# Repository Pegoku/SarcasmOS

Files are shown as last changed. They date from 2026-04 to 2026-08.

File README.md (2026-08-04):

# SarcasmOS

SarcasmOS is a personality-first voice assistant.
The core idea is simple: take a smart assistant like Alexa or Google Home, then give it a face, a voice, and most importantly, a personality. Instead of answering like a neutral corporate box, SarcasmOS replies in Spanish with dry humor, sarcasm, and animated expressions inspired by [Bender](https://futurama.fandom.com/wiki/Bender).

This project focusses on the software and AI side of the assistant, but it also includes various hardware elements, like multiple PCBs, sensors, motors, and quite a bit of 3D printing.
The goal is to have a memorable, sarcastic, and show-like assistant that can be used both for fun and real tasks like controlling smart home devices, playing music reviewing your agenda, or answering questions.

### Demo Video

Watch the SarcasmOS demo (https://www.youtube.com/watch?v=0U2ITrU95Sk)

<details>
  <summary>Do not click here</summary>

SarcasmOS striking a funny Bender pose

</details>

## Why did we Build This?

Futurama is a classic tv show we love (and you should too). Bender is the most memorable character, and his sarcastic personality is a perfect fit for a voice assistant.
We wanted to build a voice assistant that is not just a plain, neutral box, but one that has a personality and you won't just use it to get things done, but also to have fun and be entertained

## Images

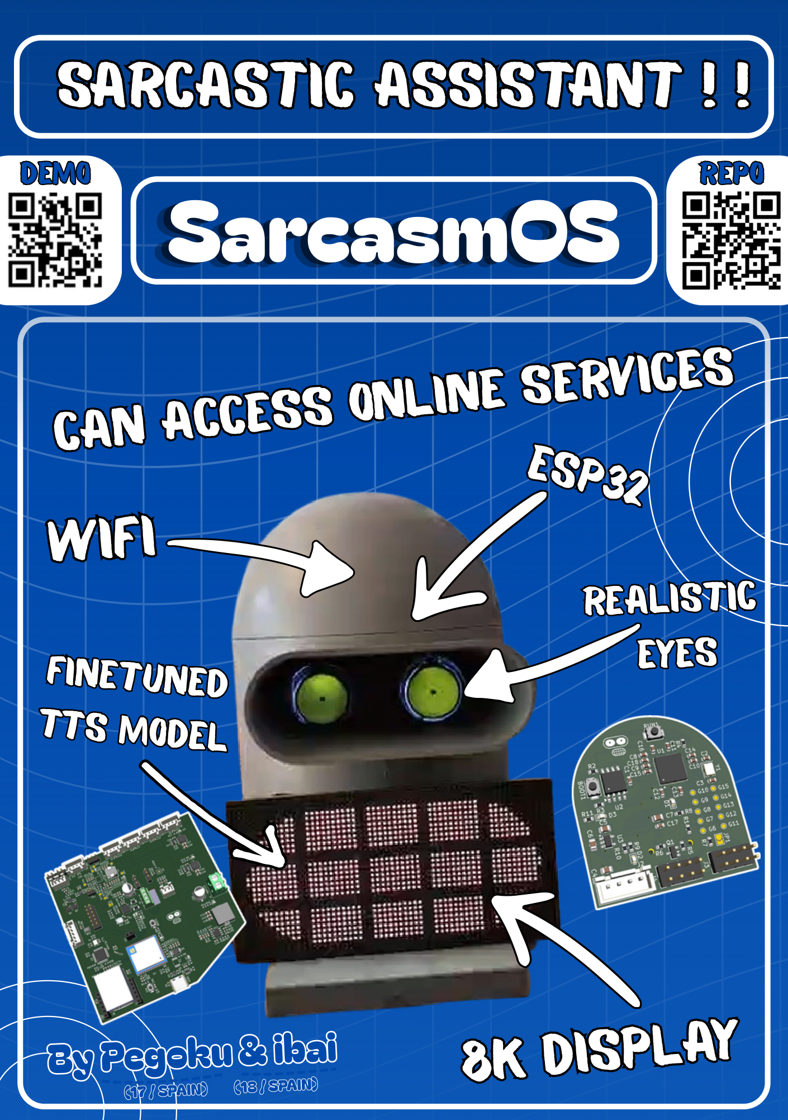
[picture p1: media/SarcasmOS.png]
SarcasmOS Poster


<details>
  <summary>CAD - click to expand</summary>
  
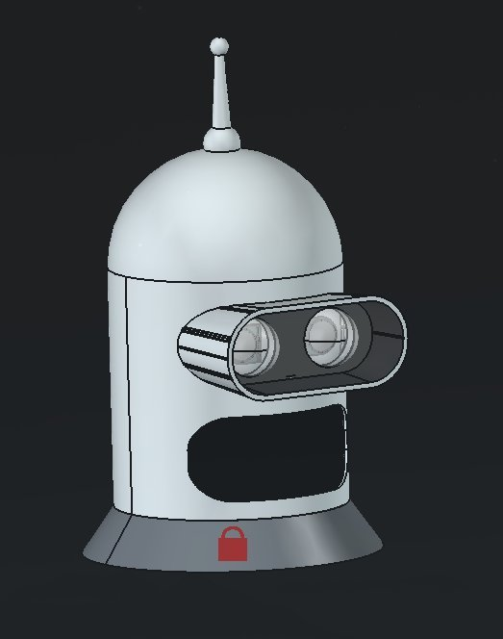
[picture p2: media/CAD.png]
CAD


</details>

### Brain PCB

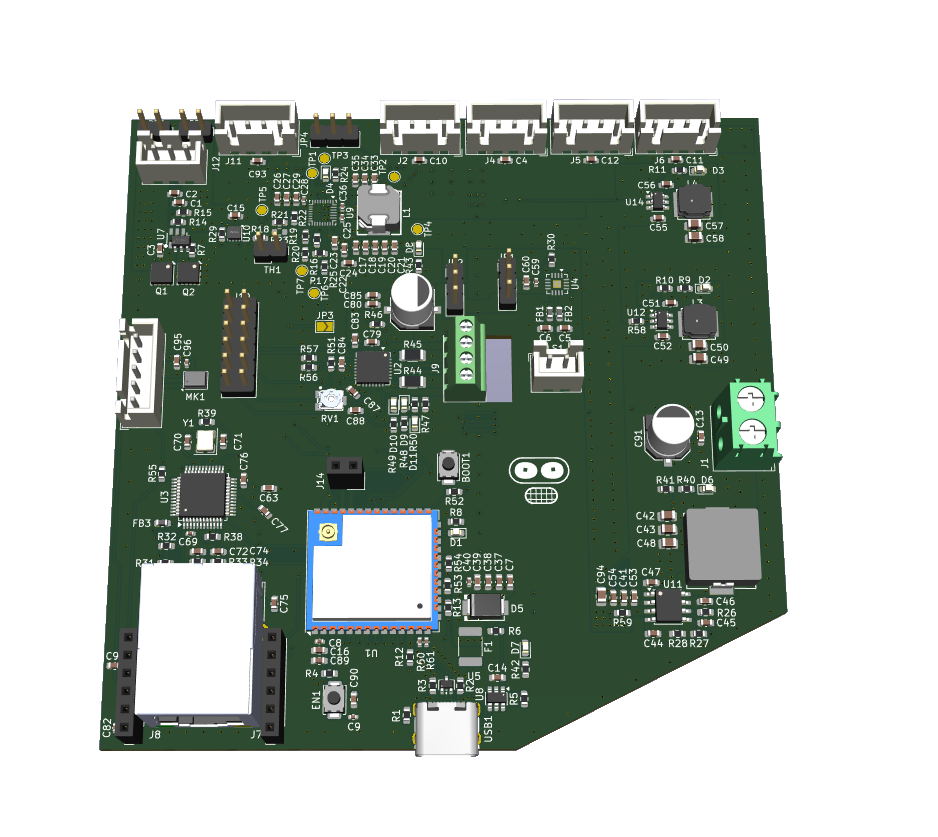
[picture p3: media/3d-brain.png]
3d brain pcb


<details>
  <summary>Brain PCB schematic - click to expand</summary>
  
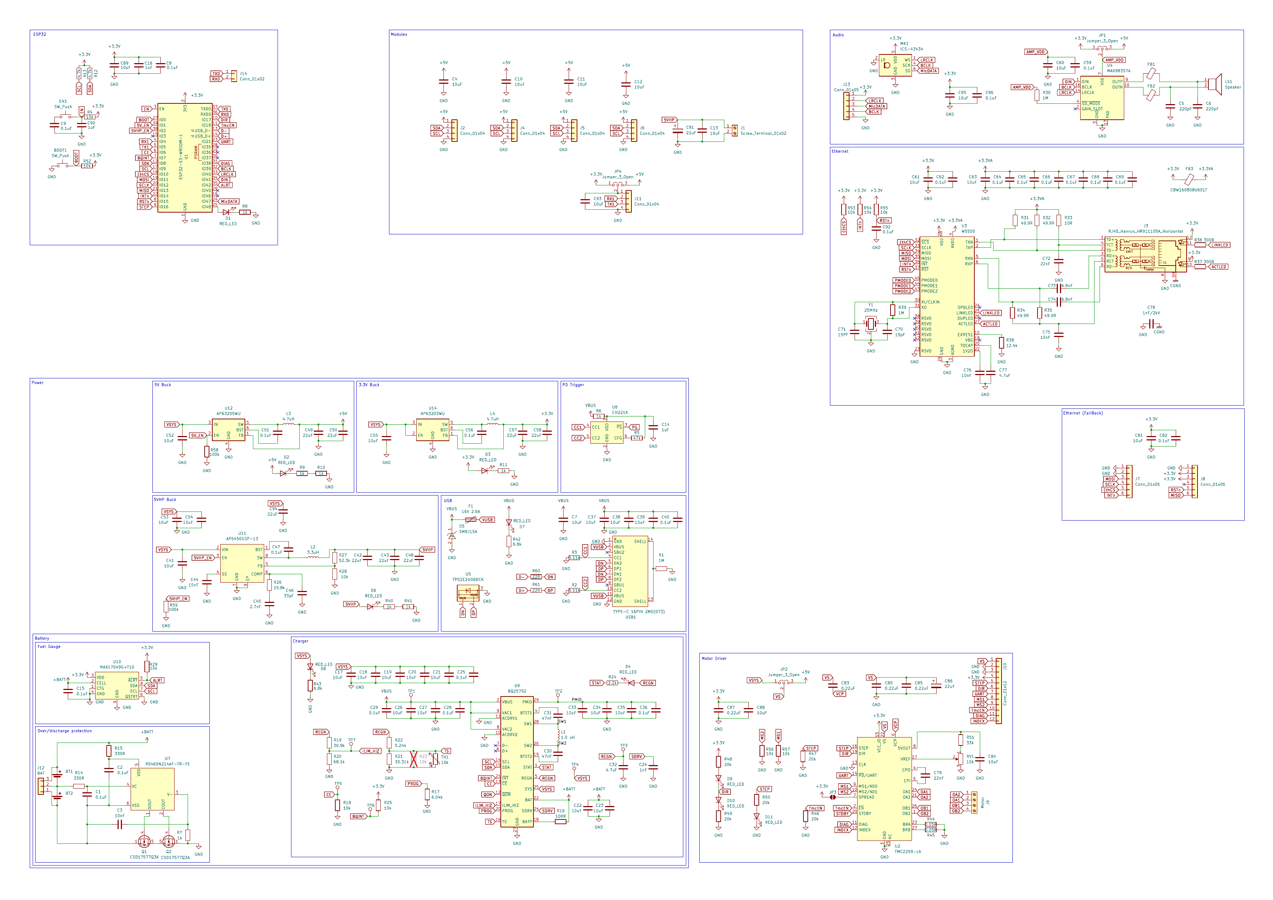
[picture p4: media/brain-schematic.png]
Brain PCB schematic


</details>

<details>
  <summary>Brain PCB layout - click to expand</summary>

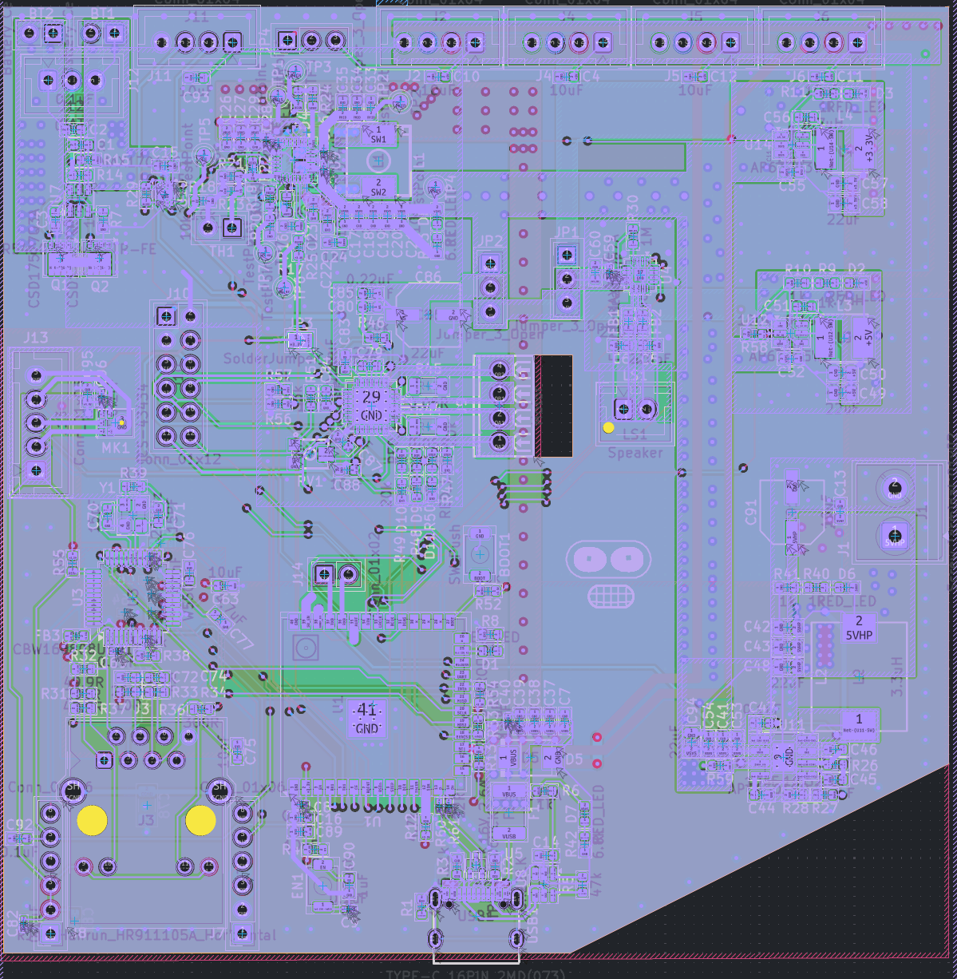
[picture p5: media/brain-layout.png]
Brain PCB layout


</details>

### Eye PCB

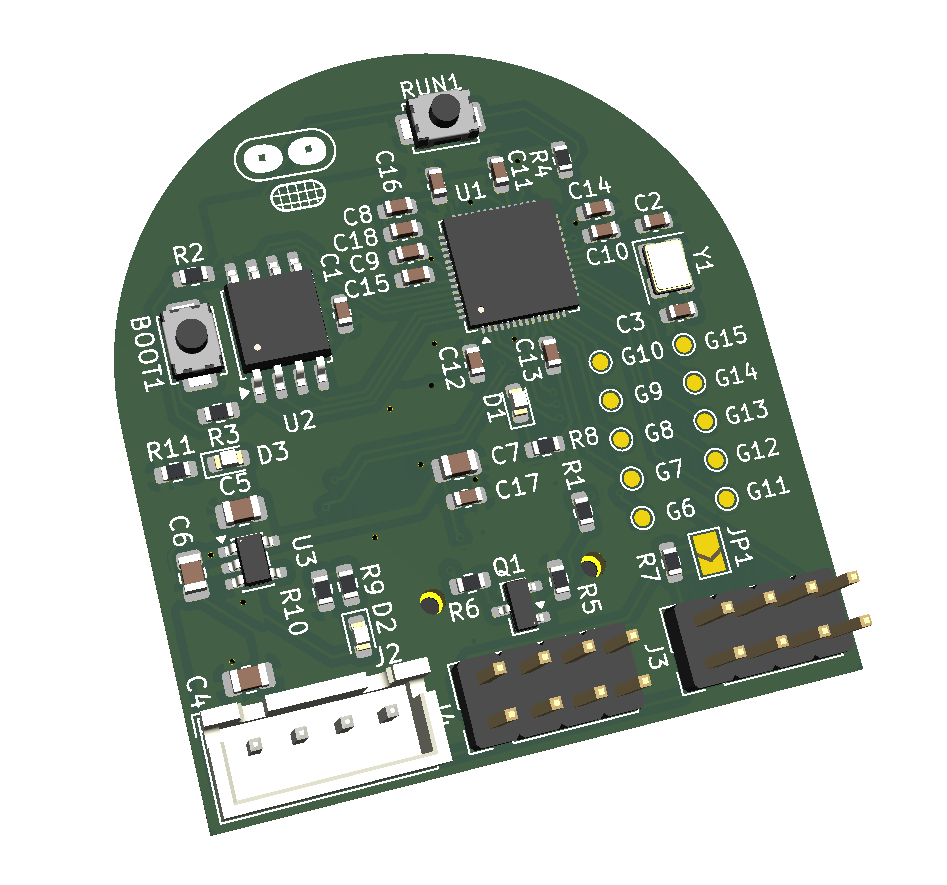
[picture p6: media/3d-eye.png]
3d eye pcb


<details>
  <summary>Eye PCB schematic - click to expand</summary>
  
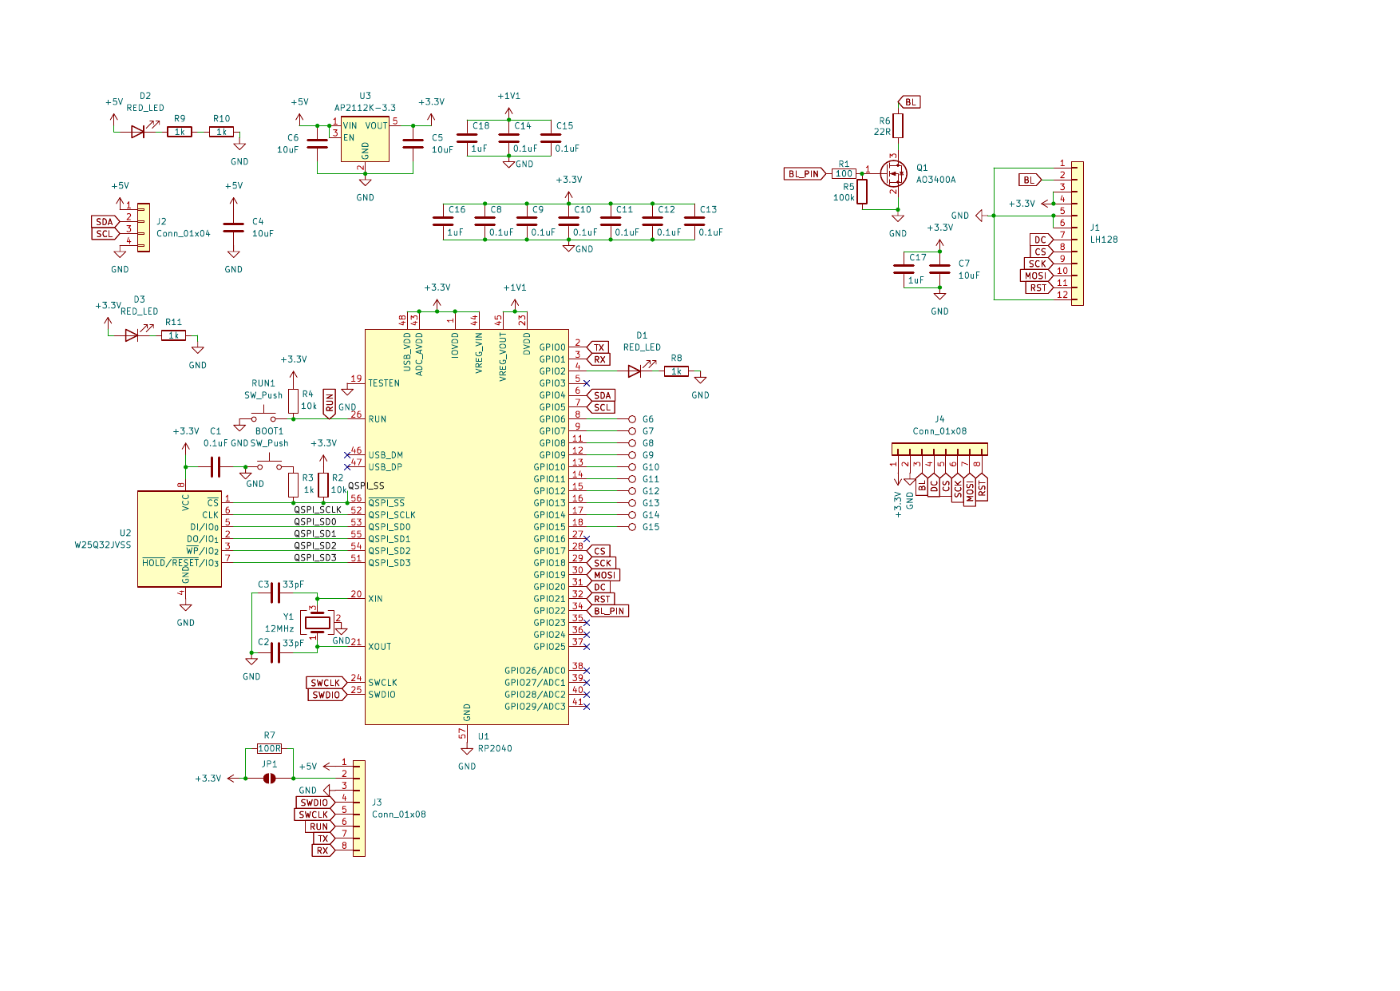
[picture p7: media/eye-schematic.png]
Eye PCB schematic


</details>

<details>
  <summary>Eye PCB layout - click to expand</summary>

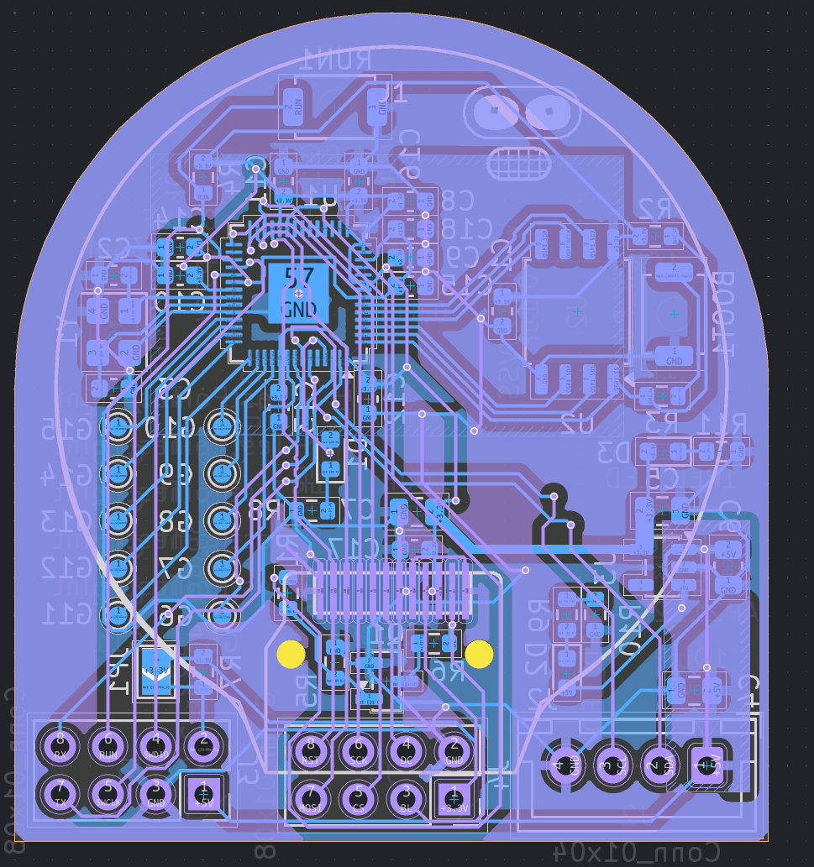
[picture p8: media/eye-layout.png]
Eye PCB layout


</details>

### Mouth PCB

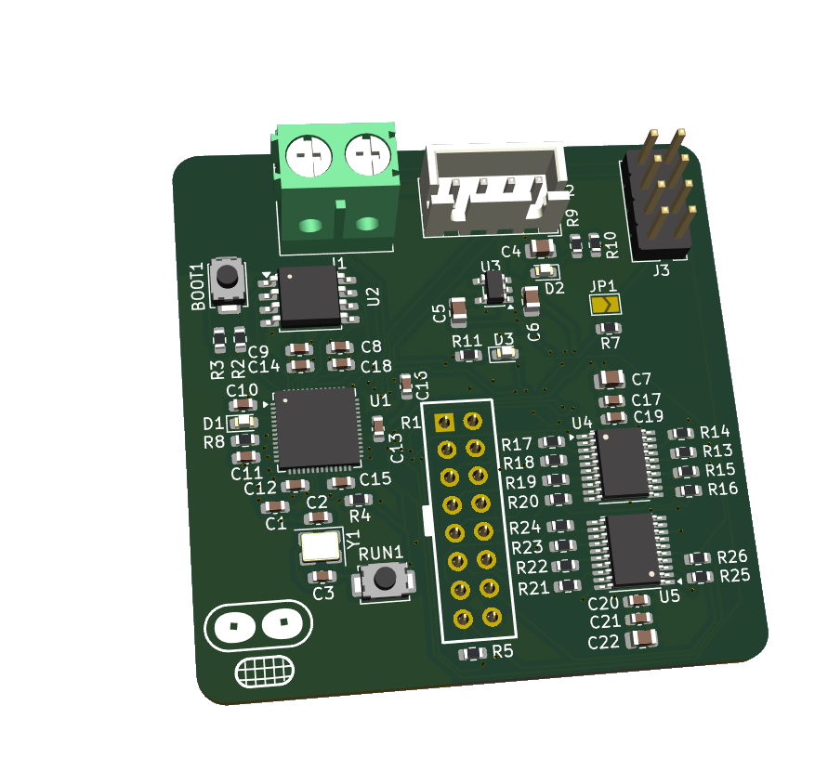
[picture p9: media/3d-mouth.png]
3d mouth pcb


<details>
  <summary>Mouth PCB schematic - click to expand</summary>

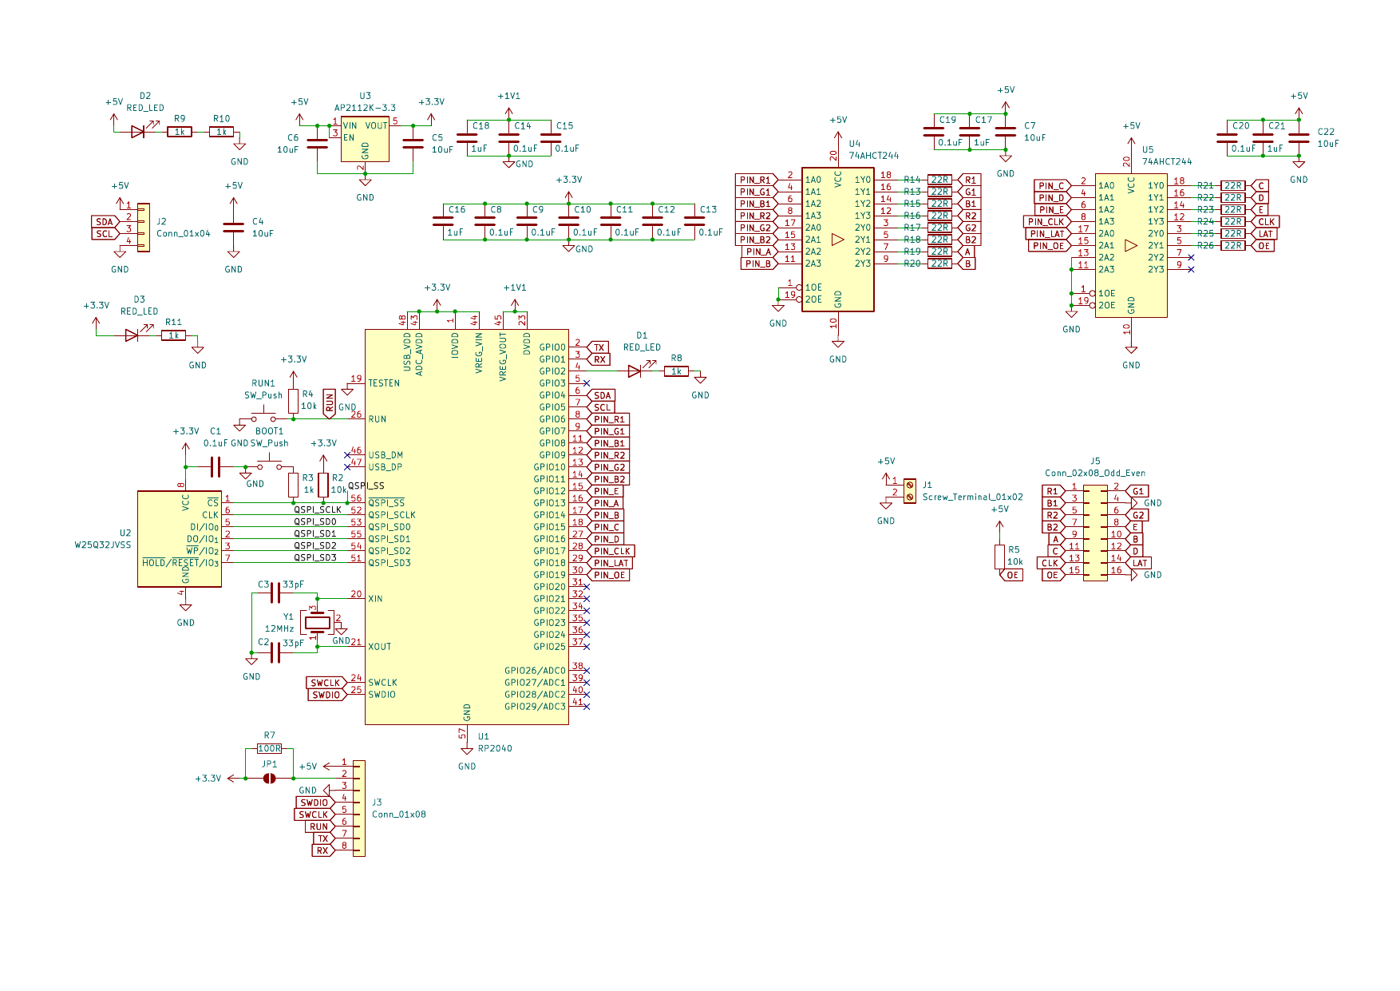
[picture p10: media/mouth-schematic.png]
Mouth PCB schematic


</details>

<details>
  <summary>Mouth PCB layout - click to expand</summary>
  
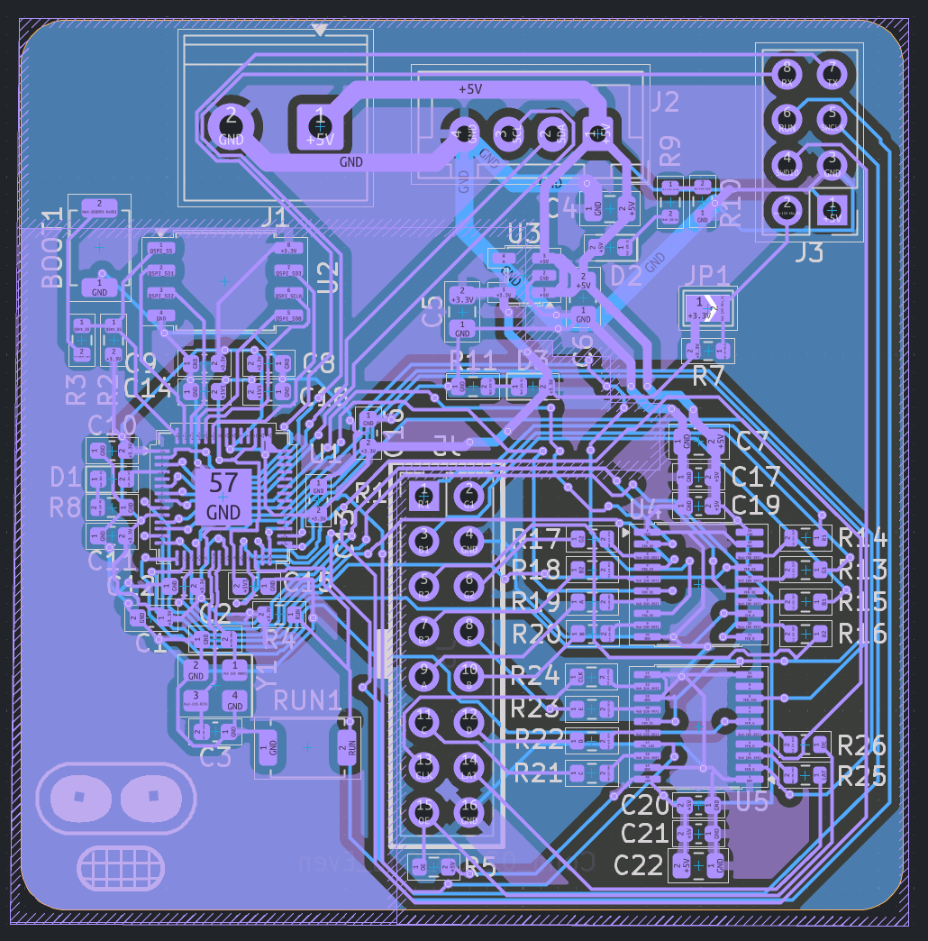
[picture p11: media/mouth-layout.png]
Mouth PCB layout


</details>

## Language Scope

SarcasmOS is designed to work in Spanish first.

The language model prompt, personality, expected user input, and generated responses are all tuned for Spanish. Other languages may work accidentally depending on the upstream model, but they are outside the intended behavior of this project.

## Features

- Listens to speech input.
- Transcribes speech to text.
- Generates Spanish answers with a sarcastic character voice.
- Converts the answer back to speech.
- Syncs audio playback with an animated face.
- Stores memory of past interactions.
- Has a web interface for chat, audio, history and configuration.
- Has integrated speaker and microphone.
- Custom animations for the eyes and mouth.
- _8k mouth display_ (128x64 pixels = 8192 pixels).

## BOM

> It is recommended to use the online [google spreadsheet](https://docs.google.com/spreadsheets/d/1oUawWcxpkl1FgnUkY16h-4gWlRbnDHgNzrJ1ZsR5Gkk/edit?usp=sharing) for the most up to date BOM with links and prices.

<details>
  <summary>Click to expand the BOM table</summary>

| Item | Desc | Qtty needed | Qtty / Pack | Pack Qtty | Price / pack | Source | Extra | Category | Already owned | In Cart | Purchased | Item Total | Final Total | Final Total ($) |
| --- | --- | --- | --- | --- | --- | --- | --- | --- | --- | --- | --- | --- | --- | --- |
| Round Display | Eyes | 2 | 2 | 1 | 6.55€ | https://es.aliexpress.com/item/1005006928550245.html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 | | Eyes | FALSE | TRUE | FALSE | 6.55€ | 269.90€ | $309.64 |
| Display Lens | Make Eyes Bigger | 2 | 1 | 2 | 19.69€ | https://es.aliexpress.com/item/1005008724449296.html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 | | Eyes | FALSE | FALSE | FALSE | 39.38€ | | |
| Flexible LED Matrix | Mouth | 1 | 2 | 1 | 39.56€ | https://es.aliexpress.com/item/1005006068032826.html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 | | Mouth | FALSE | FALSE | FALSE | 39.56€ | | |
| Microphone module | Fallback PCB | 1 | 1 | 1 | 6.30€ | https://es.aliexpress.com/item/1005009698505728.html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 | | Brain | FALSE | FALSE | FALSE | 6.30€ | | |
| Ethernet module | Fallback PCB | 1 | 1 | 1 | 4.35€ | https://es.aliexpress.com/item/1005009204216561.html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 | | Brain | FALSE | FALSE | FALSE | 4.35€ | | |
| 18650 cells | | 14 | 1 | 14 | 0.00€ | Already owned | | Brain | TRUE | FALSE | FALSE | 0 | | |
| cable | | 1 | 1 | 1 | 0.00€ | Already owned | | Brain | FALSE | FALSE | FALSE | 0.00€ | | |
| mmWave sensor | | 1 | 1 | 1 | 4.79€ | https://es.aliexpress.com/item/1005006121923099.html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 | | Brain | TRUE | FALSE | FALSE | 0 | | |
| Stepper Motor | Nema17 17HS4023 42BGYH | 1 | 1 | 1 | 5.19€ | https://es.aliexpress.com/item/1005003874936862.html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 | | Brain | FALSE | FALSE | FALSE | 5.19€ | | |
| Antenna | For esp32 | 1 | 1 | 1 | 1.84€ | https://es.aliexpress.com/item/1005007468291772.html | | Brain | FALSE | FALSE | FALSE | 1.84€ | | |
| Speakers | Speakers | 1 | 2 | 1 | 5.47€ | https://es.aliexpress.com/item/1005008326457654.html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 | | Brain | FALSE | FALSE | FALSE | 5.47€ | | |
| LCSC components | Components | 1 | 1 | 1 | 93.44€ | https://www.lcsc.com | https://docs.google.com/spreadsheets/d/1oUawWcxpkl1FgnUkY16h-4gWlRbnDHgNzrJ1ZsR5Gkk/edit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 | Brain, Mouth, Eyes | FALSE | FALSE | FALSE | 93.44€ | | |
| LCSC Shipping | Components | 1 | 1 | 1 | 14.68€ | https://www.lcsc.com | | Brain, Mouth, Eyes | FALSE | FALSE | FALSE | 14.68€ | | |
| JLCPCB PCBs | PCBs | 1 | 1 | 1 | 22.17€ | http://jlcpcb.com | | Brain, Mouth, Eyes | FALSE | FALSE | FALSE | 22.17€ | | |
| JLCPCB Shipping | PCBs | 1 | 1 | 1 | 30.97€ | http://jlcpcb.com | THIS IS THE CHEAPEST OPTION | Brain, Mouth, Eyes | FALSE | FALSE | FALSE | 30.97€ | | |

</details>

## Current State

SarcasmOS is complete, including its Brain, Eye, and Mouth firmware. The finished hardware can listen for its wake phrase, understand a spoken request, use tools, answer in a Spanish Bender-style voice, and coordinate the animated face while it works and speaks.

| Component | Capabilities |
| --- | --- |
| [Brain firmware](Code/Brain) | Runs the complete voice-assistant workflow on the ESP32-S3: microphone capture, wake-phrase detection, STT, multi-round LLM calls, TTS, speaker playback, conversation memory, a USB console, and a local HTTP API. Its native tools provide weather, local time, Google Calendar search, and live robot status. It also coordinates synchronized face transitions. |
| [Eye firmware](Code/Eye) | Drives the two 240x240 GC9A01A displays from RP2040 boards, with 31 animated expression and weather states, independent left/right artwork, brightness control, and synchronized transitions over I2C. |
| [Mouth firmware](Code/Mouth-NeonPCB) | Drives the 64x32 HUB75 RGB matrix from an ESP32-S3, with the matching 31 states, blended transitions, speaking intensity, live weather temperatures, brightness control, and acknowledged ESP-NOW communication. |
| [Web app](Code/AI/Workflow/SarcasmOS-web) | Provides an optional browser interface with chat, voice, history, configuration, and a full-face view. A hosted demo is available at [sarcasmos.pegoku.com](https://sarcasmos.pegoku.com/). |
| Hardware | Includes the finished 3D-printed enclosure, Brain/Eye/Mouth PCBs, microphone, speakers, sensors, motors, and display hardware. |

The Brain is the runtime controller: it talks to the two Eyes over I2C and to
the Mouth over acknowledged ESP-NOW. STT, LLM, and TTS remain cloud services,
but the physical assistant does not require the Python web backend to run.

## Build and Run the Firmware

Bring the boards up in this order so the Brain can be configured with the
Mouth's MAC address and matching 2.4 GHz Wi-Fi/ESP-NOW channel.

### 1. Mouth

Install [PlatformIO](https://platformio.org/), connect the Mouth ESP32-S3, and
run:

```bash
cd Code/Mouth-NeonPCB
pio run -e custom_esp32s3_mini_n8 --target upload
pio device monitor -e custom_esp32s3_mini_n8
```

At boot, note the station MAC address and ESP-NOW channel printed in the serial
monitor. The Mouth uses channel 1 by default; its onboard button can select
channels 1 through 13. It must match the Brain's Wi-Fi channel. See the
[Mouth firmware guide](Code/Mouth-NeonPCB/README.md) for local animation tests,
panel wiring, channel controls, and display emulation.

### 2. Eyes

Install the [Raspberry Pi Pico SDK](https://github.com/raspberrypi/pico-sdk),
connect each RP2040 Eye through SWD, and flash the regular I2C firmware:

```bash
cd Code/Eye
./flash.sh --left --regular --build --upload --swd-monitor
./flash.sh --right --regular --build --upload --swd-monitor
```

The left and right Eyes use I2C addresses `0x30` and `0x31`, respectively.
The helper also provides self-test and standalone animation-demo firmware. See
the [Eye firmware guide](Code/Eye/README.md) for OpenOCD setup, manual builds,
UART monitoring, alternate animation packs, and the desktop editor.

### 3. Brain

Install [ESP-IDF](https://docs.espressif.com/projects/esp-idf/en/stable/esp32s3/get-started/index.html),
connect the Brain ESP32-S3, and run:

```bash
cd Code/Brain
idf.py set-target esp32s3
idf.py menuconfig
idf.py build
idf.py flash monitor
```

Under **SarcasmOS Brain** in `menuconfig`, set the Wi-Fi credentials, provider
tokens, TTS voice ID, timezone, and the Mouth station MAC recorded above. You
can also configure the wake phrase, audio sensitivity, Eye transition timing,
and ESP-NOW channel. After flashing, the USB console can test every subsystem,
send typed or spoken requests, and update persistent configuration stored in
NVS. See the [Brain firmware guide](Code/Brain/README.md) for all settings,
console commands, API endpoints, native tools, and the independent PCB
self-test firmware.

## Web Demo

For the already setup web demo, visit [https://sarcasmos-7f3c9a2e.easyrumbo.com/](https://sarcasmos-7f3c9a2e.easyrumbo.com/).

For the best experience and no ratelimiting, run the local web app.

From `Code/AI/Workflow/SarcasmOS-web`:

```bat
start-all.bat
```

On macOS/Linux:

```bash
./start-all.sh
```

This starts:

- Proxy (combines all services into 1 port for easy access): `http://localhost:9000`
- Frontend: `http://localhost:5173`
- Backend: `http://localhost:8001`

You can also start them separately:

```bash
python -m http.server 5173
python -m uvicorn backend.app:app --host 0.0.0.0 --port 8001
```

## Configuration

The backend reads environment variables from `.env` files, especially:

- `Code/AI/Workflow/SarcasmOS-web/backend/.env`
- `Code/AI/Workflow/.env`

**Important variables**:

- `HACK_CLUB_AI_KEY`, or separate provider keys.
- `OPENROUTER_API_TOKEN` for the language model.
- `REPLICATE_API_TOKEN` for STT/TTS if using Replicate.
- `MINIMAX_VOICE_ID` for the TTS voice.
- `FFMPEG_PATH` if `ffmpeg` is not available on PATH.

More technical detail:

- `Code/AI/Workflow/SarcasmOS-web/README.md`
- `Code/AI/Workflow/SarcasmOS-web/PROJECT_OVERVIEW.md`

## Architecture

```text
Microphone / wake phrase / text request
                  |
                  v
          ESP32-S3 Brain
           |      |      \
           |      |       +--> Cloud STT, LLM/tools, and TTS
           |      |
           |      +----------> Mouth over ESP-NOW
           |
           +-----------------> Left + right Eyes over I2C
                  |
                  v
       Speaker audio + synchronized animated face
```

## Things that happened when carrying out the project

When it came to making our project a reality we had several problems, because of customs we had to pay almost $200 more than what we had budgeted. We ended up paying more than $600 for the project 😭

When we ordered the electronic components, 4 were missing, for some reason. We told the company and they sent us the missing components (they were less than $1). When they arrived, which they did way after we finshed the project, and they wanted us to pay customs more than $16 for $0.80 of chips...

The flexible display we wanted to use also got lost in the mail, and we had to pay $60 for one, but it didn't arrive either. We ended up using a different display and driver, which we already had from a previos Hackclub YSWS (Neon).

## Credits

Built as a physical AI assistant project for Hack Club / Fallout.
SarcasmOS is not trying to be polite. It is trying to be memorable.

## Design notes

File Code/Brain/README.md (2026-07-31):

# SarcasmOS Brain Firmware

ESP-IDF firmware for the ESP32-S3 brain PCB.

## Features

- Enables the `+5V` and `5VHP` rails at boot.
- Uses I2C on `IO8`/`IO9` at 400 kHz by default.
- Controls the left eye at I2C `0x30`, the right eye at I2C `0x31`, and the
  mouth through acknowledged ESP-NOW unicast.
- Coordinates animation transitions: both eyes receive a transition token and
  finish their outgoing animation independently, report READY, then receive a
  back-to-back `CMD_SYNC` commit with a 50 ms future start deadline. The mouth
  is released after the committed eyes confirm activation. If one eye is
  absent or times out, the ready eye is committed and the transition is marked
  degraded instead of remaining frozen.
- Implements the packet protocol from `PCB/FIRMWARE_PLAN.md`, including CRC-8.
- Starts Wi-Fi station mode when configured.
- Runs the complete assistant orchestration on the ESP32. There is no
  SarcasmOS backend process to run on another computer.
- Serves the device and AI API itself: `GET /api/status`,
  `GET /api/config`, `POST /api/command`, `POST /api/ai/text`, and
  `POST /api/ai/listen`.
- Provides a three-page USB console in the regular firmware for tests, manual
  interaction, and persistent configuration.
- Runs the ICS-43434 and MAX98357A in full-duplex 32-bit Philips I2S mode.
- Streams microphone PCM directly from the ESP32 to the configured STT
  provider and streams Bender WAV responses directly to the speaker without
  requiring PSRAM.
- Runs wake-phrase recognition, random acknowledgements, silence detection,
  STT, the multi-round LLM/tool loop, short progress TTS before every tool,
  final TTS, and bounded in-RAM conversation memory on the ESP32.
- Calls weather, time, Google Calendar, robot status, LLM, STT, and TTS
  services directly from the ESP32 over TLS.
- Drives listening/thinking/tool/speaking face states. Real weather results
  select the matching weather face and write the temperature to the Mouth.

## Build

```sh
idf.py set-target esp32s3
idf.py menuconfig
idf.py build
idf.py flash monitor
```

This PCB has 16 MB flash. The project uses [`partitions.csv`](partitions.csv)
with a 4 MB factory partition.

Set optional defaults under `SarcasmOS Brain` in `menuconfig`. Copy the station
MAC printed by the mouth firmware into `ESP-NOW mouth station MAC`. If the
Brain does not join an access point, configure both boards for the same fixed
ESP-NOW channel. If it does join Wi-Fi, build the mouth for that access point's
2.4 GHz channel.

## Regular firmware USB console

The normal firmware accepts input through USB serial. Input is echoed
immediately and one prompt is printed per command. Enter `h` at `brain>`:

```text
1  Testing
2  Interact
3  Configuration
```

The Testing page scans I2C, reads both Eyes, pings the ESP-NOW Mouth, reports
network and power status, plays a speaker tone, and measures the microphone.
It also gates the live microphone WebSocket:

```text
stream on
stream status
mic gain 2.00
mic sensitivity 600
stream off
```

Enter `p` on the Testing page for the interactive speaker controller. Use
Up/Down or `W`/`S` to choose approximately 0.05 W through 3.2 W, Space/Enter
to preview a one-second tone, `A` to apply and save that level as the default
for tests and TTS, and `Q`/Esc to return. Levels above 1.5 W require explicit
confirmation. Power estimates assume a 4-ohm speaker, 5 V amplifier supply,
and the PCB's fixed 9 dB MAX98357A gain. `GAIN_SLOT` is not connected to the
ESP32, so firmware changes digital amplitude/dBFS rather than hardware gain.

The `/api/audio/mic` route does not exist until `stream on` is entered. Turning
it off unregisters the route and disconnects its client. This setting is
intentionally runtime-only and returns to disabled after a reboot.
Microphone gain and sensitivity are persistent and shared by the level test,
live stream, wake detection, and STT capture. Gain accepts `0.25` to `8.00`;
larger values make the PCM louder but also amplify noise and may clip. The
sensitivity value is the VAD amplitude threshold, so a lower value detects
quieter speech.

The Interact page sends face states, changes brightness, controls both bucks,
starts a microphone request with `listen`, and accepts a typed request with
`ask <message>`. Individual provider stages can be tested without running the
rest of the workflow:

```text
stt-test 5
llm-test Responde solamente con la palabra funciona
tts-test Esto es una prueba de la voz de Bender
```

The STT command records for up to the requested number of seconds and prints
the transcript. LLM prints the provider response without tools or TTS. TTS
synthesizes and plays the supplied text without calling STT or the LLM.

Configuration is stored in NVS and overrides build-time defaults, including
when those defaults are blank:

```text
show
view stt-model
view mic-gain
set ssid MyNetwork
set password MyPassword
set ai-token your-shared-Hack-Club-AI-token
set llm-token optional-different-LLM-token
set replicate-token optional-different-STT-TTS-token
set llm-url https://ai.hackclub.com/proxy/v1
set replicate-url https://ai.hackclub.com/proxy/v1/replicate
set llm-model ~anthropic/claude-sonnet-latest
set stt-model vaibhavs10/incredibly-fast-whisper:VERSION
set tts-model minimax/speech-2.8-turbo
set voice-id your-Minimax-Bender-voice-id
set calendar-token optional-Google-OAuth-access-token
set timezone Europe/Madrid
set wake oye bender
set wake-enabled on
set silence-ms 5000
set vad 1200
set mic-gain 1.00
apply-wifi
```

`llm-url` normally contains the API base URL. For compatibility, the firmware
also accepts a full URL ending in `/chat/completions` and will not append the
path a second time.

The specific LLM and Replicate tokens fall back to `ai-token` when blank.
`show` and `view <key>` print actual values, including passwords, tokens, and
voice IDs; avoid sharing or recording that serial output. Wi-Fi changes can be
applied immediately; AI settings are picked up by the next interaction.
Configuration is stored in NVS. Enable NVS encryption for a production unit
because provider and Calendar tokens otherwise remain plaintext in flash.

## ESP32-native AI workflow

The runtime architecture is:

```text
microphone -> ESP32 Brain -> STT -> LLM/tool loop -> Bender TTS -> speaker
                         |-> Eyes over I2C
                         |-> Mouth over ESP-NOW
USB CLI / local HTTP ----^
```

The STT/LLM/TTS providers are cloud services, but the ESP32 is the client,
workflow engine, hardware controller, and local HTTP server. The Python code
under `../AI/Workflow` is not a runtime dependency.

Local VAD waits for speech before opening the HTTPS STT request. The ESP32
compares the returned transcript with the configured wake phrase. This avoids
embedding a WakeNet model, but each spoken candidate uses one transcription
request and requires Wi-Fi. Leave `wake-enabled` off to use only manual
`listen`.

After a wake match, the Brain plays one randomly selected Bender TTS
acknowledgement, then records the request until the configured silence interval
(5 seconds by default). Tool calls stream related Bender progress phrases
while they run. Weather results pass the real temperature to Mouth `SET_PARAM`
key `2`; fabricated temperatures are never displayed.

The native tools are:

- `get_weather`, using `wttr.in`;
- `get_time`, using the configured IANA timezone;
- `robot_status`, using live Eye, Mouth, network, microphone, and speaker
  state from this firmware;
- `google_calendar_search`, using the optional OAuth access token stored in
  NVS.

Google access tokens can expire. Replace `calendar-token` when Google returns
an expired-permission response.

Normal face changes use a one-element overwrite queue. Rapid requests replace
an obsolete pending target, Eye protocol-v2 status is polled every 20 ms, and
the mouth receives the target only after both eyes report the matching active
animation/token with no pending animation. The default barrier timeout is
2500 ms and the mouth blend duration is 200 ms; both are configurable under
`SarcasmOS Brain`. Error, sleep, and battery-critical animations explicitly
bypass the graceful barrier.

If an Eye does not reach READY or confirm activation before the first barrier
timeout, Brain resends the request to both Eyes with a fresh transition token
and repeats the complete READY/commit barrier once. The mouth does not receive
the animation until that retry finishes or also times out.

`GET /api/status` includes `face_transition`, detailed active/pending Eye
status, and Mouth transition token/progress. Mouth application-v2 status is
accepted during migration but does not provide blend progress. Eye protocol-v1
status cannot satisfy the barrier and therefore produces a logged degraded
transition after the timeout.

## ESP32 HTTP API

The API is served by the ESP32 at `http://DEVICE_IP/`:

```sh
curl http://DEVICE_IP/api/status
curl http://DEVICE_IP/api/config
curl -X POST http://DEVICE_IP/api/command \
  -H 'Content-Type: application/json' \
  -d '{"animation":"speaking"}'
curl -X POST http://DEVICE_IP/api/ai/text \
  -H 'Content-Type: application/json' \
  -d '{"message":"¿Qué tiempo hace en Madrid?"}'
curl -X POST http://DEVICE_IP/api/ai/listen
```

`/api/ai/text` runs the complete model/tool/TTS workflow and returns the final
answer as JSON after it has played it. `/api/ai/listen` records from the
device microphone and does the same. Only one voice workflow can own the
microphone/speaker at a time.

### Live microphone WebSocket

After enabling it from the Testing page, connect to:

```text
http://DEVICE_IP/api/audio/mic
```

That URL serves a small built-in player. Press **Start listening** to satisfy
the browser's audio permission/autoplay requirement. A custom website can
connect directly to:

```text
ws://DEVICE_IP/api/audio/mic
```

The page also exposes persistent gain and speech-threshold controls. They take
effect immediately after **Apply and save** and stay synchronized with values
changed from USB serial. The first WebSocket message is JSON describing the
stream and current settings. Following messages are binary frames containing
signed little-endian PCM with this fixed format:

```json
{"format":"pcm_s16le","sample_rate":16000,"channels":1,"frame_samples":1600,"gain_q8":256,"gain":1.00,"vad_threshold":1200}
```

A custom WebSocket client can update both values with a text frame. Values are
saved in NVS, and the server replies with the resulting settings:

```json
{"gain_q8":512,"vad_threshold":600}
```

That is one 100 ms, 3,200-byte frame under normal operation. A browser should
set `binaryType = "arraybuffer"`, convert each message to `Int16Array`, scale
samples by `1 / 32768`, and queue them in an `AudioWorklet` running at the
browser audio context's sample rate. Only one WebSocket listener is accepted.
Wake detection is suspended while the endpoint is enabled, and the stream has
exclusive microphone/audio access while a client is connected.

### Local wake-word dataset and training TUI

`tools/wakeword_tui.py` connects directly to that WebSocket and builds a
resumable, labeled dataset from the microphone fitted to the Brain PCB. Enable
the endpoint from the Testing page before starting it:

```text
brain/test> stream on
```

The collector has no third-party dependencies. Launch the TUI with:

```bash
python tools/wakeword_tui.py --device 192.168.1.125 \
  --phrase "oye bender"
```

The guided collection covers positive wake-phrase examples, negative/confusing
speech, varied background noise, and quiet microphone noise. Completed WAV
files and progress survive disconnects under the ignored `wakeword_data/`
directory. The configuration page can change every sample count and duration.

Choose **Setup** once to clone the upstream Open Home Foundation
microWakeWord trainer and create an isolated TensorFlow environment, then
choose **Train**. TensorFlow requires Python 3.10 through 3.13; Setup prefers a
compatible installed interpreter (override it with `MWW_PYTHON`) and otherwise
uses `uv` to install an isolated Python 3.12 automatically. Training then:

1. splits the recordings into training, validation, and test sets;
2. augments positives with the captured noise environments;
3. generates microWakeWord spectrogram features;
4. trains and evaluates a streaming MixedNet model; and
5. exports a quantized `.tflite` model plus ESPHome-compatible JSON metadata
   under `wakeword_data/models/`.

TensorFlow training can take hours without a supported GPU. The exported model
is the input for the local ESP32 inference integration; producing it does not
by itself replace the current Whisper-based wake listener in this firmware.

## PCB self-test firmware

An independent bring-up firmware is available in [`self_test/`](self_test/).
It reports Wi-Fi, buck-control, I2C power-management and eye devices, the
ESP-NOW mouth, W5500, GPIO, and I2S audio checks through native USB serial, then
opens an interactive menu for manual power, speaker, microphone, and individual
eye/mouth visual tests. See
[`self_test/README.md`](self_test/README.md) for build, flash, and test details.

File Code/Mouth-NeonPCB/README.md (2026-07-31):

# SarcasmOS ESP32-S3 mouth

Arduino C++ firmware for the custom ESP32-S3-MINI-1-N8 driver PCB and one
64x32, 1/16-scan HUB75 RGB panel. It renders the same mouth states as
`../Mouth`, but receives commands wirelessly over ESP-NOW instead of I2C.

The complete Workflow-derived visual and state contract is documented in
[`MOUTH_STATES.md`](MOUTH_STATES.md).

Supported commands are ping, device info, brightness, animation/expression,
animation phase sync, stop, speaking intensity, weather temperature, and
reset. Every valid command gets a status response carrying its sequence
number and result.

Animation changes use a 200 ms RGB blend by default. The regular firmware
accepts an optional Brain-assigned transition token and duration so the Brain
can wait for both eyes before starting the mouth transition. The local tester
uses the same blend when selecting or automatically advancing states.

## Firmware variants

The project produces two separate firmware images that share the same panel
driver, pin map, and animation renderer:

- `custom_esp32s3_mini_n8`: regular firmware with ESP-NOW control.
- `local_animation_test`: standalone tester with no brain or wireless link
  required.

### Regular ESP-NOW firmware

```sh
pio run -e custom_esp32s3_mini_n8
pio run -e custom_esp32s3_mini_n8 --target upload
```

At boot the serial monitor prints the mouth's Wi-Fi station MAC address and
ESP-NOW channel. Record that MAC for the brain configuration.

The factory channel defaults to `1`. Change `-DESPNOW_CHANNEL=1` in
`platformio.ini` to build with a different initial value. The regular ESP-NOW
firmware also uses the PCB's active-low GPIO0 button:

- release a short press to advance one channel (`1` through `13`, wrapping
  from `13` to `1`);
- hold it for 1.2 seconds to reset the channel to `1`; the reset occurs while
  the button is still held and does not advance again on release.

The selected channel is stored in NVS and overrides the build default on later
boots. Each successful change displays a centered yellow `CH n` notice on the
LED matrix for 1.2 seconds. GPIO0 is also the ESP32 boot strap: perform a long
press only after the board has booted, not while resetting or applying power.

Changing the mouth channel immediately retunes its radio. The Brain must use
the same channel or communication stops until their channels match again.

### Local animation-test firmware

```sh
pio run -e local_animation_test
pio run -e local_animation_test --target upload
pio device monitor -e local_animation_test
```

The local tester cycles through every supported state so visual changes can
be checked without the Brain. Its serial controls are:

| Key | Action |
| --- | --- |
| `0`..`9` | select one animation |
| Left arrow | select the previous state and pause autoplay |
| Right arrow | select the next state and pause autoplay |
| `a` | toggle automatic all-state cycling |
| `n` | advance to the next state |
| `p` | cycle red, green, blue, white, color bars, RGB rows, and geometry tests |
| `+` / `-` | adjust brightness |
| `]` / `[` | adjust speaking intensity |
| `.` / `,` | adjust the weather-test temperature by 1°C |
| `h` | print help |

Uploading one variant replaces the other in flash. Re-upload the regular
environment when local testing is complete.

## Desktop display emulator

The dependency-free desktop emulator opens a scaled window representing the
physical 64x32 panel:

```sh
./emulator.py
```

The emulator and firmware consume the same source-of-truth asset pack:
[`assets/mouth_assets.json`](assets/mouth_assets.json). It contains every
native 64x32 sprite, frame sequence, playback mode, and frame duration.
State selection uses the same 200 ms blend as the physical firmware. Press
`x` to disable transitions while inspecting or editing exact source frames,
or launch with `--no-transitions`.
The live temperature glyphs are likewise shared through
[`assets/temperature_font.json`](assets/temperature_font.json). PlatformIO
regenerates their C++ headers before building the firmware.

Left and Right select states and pause playback. Space or `a` toggles playback,
including both automatic state changes and animation frames. While paused, Up
selects the next frame and Down selects the previous frame. `+`/`-` changes
brightness, `[`/`]` changes speaking intensity, and `q` exits.
`,`/`.` changes the test temperature shown on the five weather states.

The editor controls operate on the exact animation frame currently displayed:

- `e` or **Open frame in GIMP** exports the native 64x32 sprite and opens it.
  Overwrite the PPM in GIMP and the emulator automatically detects, imports,
  and displays the edit.
- `o` or **Open animation in GIMP** exports and opens every frame of the
  selected animation. Each overwritten frame is imported automatically.
  In its animation folder, add a numbered PPM to append a frame or delete a
  PPM to remove that frame. The sequence and filenames are compacted
  automatically (`watch-frame-01.ppm`, `watch-frame-02.ppm`, and so on).
- `i` or **Import saved edit** manually reimports the most recently opened
  frame if an explicit refresh is needed.
- `c` or **Copy frame** puts a native-resolution PNG on the Wayland clipboard.
- `r` or **Reload assets** reloads changes made outside the emulator.
- **Add frame after current** or `Insert` creates an independent copy of the
  displayed frame immediately after it and selects the new frame. Later frames
  shift forward by one position.
- **Remove current frame** or `Delete` deletes the displayed frame and shifts
  later frames backward. An animation cannot be reduced below one frame.
- **Set frame time** or `T` changes the delay between frames for the current
  animation. Enter the delay in milliseconds; it is shared by the emulator
  and generated firmware.
- **Sync folder** or `S` imports the current animation's existing numbered PPM
  files from `/tmp/sarcasmos-mouth-edit/animations/<state>`, reloads the
  preview, and attaches that folder to the running auto-import watcher.

Start paused on a particular state with:

```sh
./emulator.py --state sarcastic --paused
```

The renderer can also be validated on a machine without a graphical session:

```sh
./emulator.py --self-test
./emulator.py --state speaking --dump speaking.ppm
./emulator.py --state snowy --temperature=-10 --dump snowy-minus10.ppm
```

Sprites can also be managed without opening the GUI:

```sh
./asset_tool.py export angry angry.ppm
./asset_tool.py import angry angry.ppm
./asset_tool.py validate
./asset_tool.py compile
```

See [`assets/README.md`](assets/README.md) for the asset format and editing
workflow. Do not edit `generated/mouth_assets.hpp` manually.

ESP-IDF QEMU has an optional virtual RGB framebuffer, but the Arduino HUB75
DMA driver used here does not target that virtual peripheral. The desktop
emulator avoids a second ESP-IDF-specific display driver and starts without an
ESP toolchain.

## Display behavior

The firmware starts with Bender's pale-yellow tooth grille. IDs `0x00` through
`0x09` preserve the legacy SarcasmOS assignments; the remaining IDs cover the
complete Workflow state set:

| ID | State |
| ---: | --- |
| `0x00` | idle |
| `0x01` | listening |
| `0x02` | thinking |
| `0x03` | thinking with audio |
| `0x04` | long thinking |
| `0x05` | speaking |
| `0x06` | happy |
| `0x07` | angry |
| `0x08` | error |
| `0x09` | sleep |
| `0x0a` | tool |
| `0x0b` | left |
| `0x0c` | right |
| `0x0d` | up |
| `0x0e` | down |
| `0x0f` | center |
| `0x10` | neutral |
| `0x11` | sarcastic |
| `0x12` | suspicious |
| `0x13` | tired |
| `0x14` | surprised |
| `0x15` | bored |
| `0x16` | dramatic |
| `0x17` | watch |
| `0x18` | party |
| `0x19` | battery low |
| `0x1a` | sunny |
| `0x1b` | rainy |
| `0x1c` | cloudy |
| `0x1d` | stormy |
| `0x1e` | snowy |

Brightness defaults to `64/255`. `SET_PARAM` key `1` controls speaking mouth
intensity. Key `2` carries a signed int8 temperature in degrees Celsius.
Weather states render that value as centered black `°C` text over every
animation frame. `-128` means unavailable and suppresses the overlay; the
regular firmware starts in that unavailable state so it never invents a
reading. Gaze-only states deliberately retain the neutral resting mouth,
because gaze affects the eyes rather than replacing the mouth expression.
Detailed behavior is described in `MOUTH_STATES.md`.
For a beginner-friendly explanation of every state's meaning, cause, lifetime,
animation timing, aliases, and current integration status, see
[`MOUTH_STATE_GUIDE.md`](MOUTH_STATE_GUIDE.md).

## ESP-NOW packet format

All multi-byte payload values are little-endian. Packets are variable length:

| Offset | Size | Meaning |
| ---: | ---: | --- |
| 0 | 2 | ASCII magic `SM` |
| 2 | 1 | transport version (`1`) |
| 3 | 1 | type: command `1`, status `2` |
| 4 | 1 | role: mouth `2`, or any role `255` |
| 5 | 1 | sequence |
| 6 | 1 | command |
| 7 | 1 | payload length, `0..64` |
| 8 | N | payload |
| 8+N | 1 | CRC-8/ATM over all previous bytes |

CRC uses polynomial `0x07`, initial value `0`, no reflection, and no final
XOR. Command IDs and packet helpers are in `protocol.hpp`.

`SET_PARAM` payloads currently are:

| Key | Value byte |
| ---: | --- |
| `1` | speaking intensity, unsigned `0..255` |
| `2` | temperature in °C, signed int8 (`-127..127`); `-128` hides it |

Send key `2` before selecting a weather animation. The value persists across
`sunny`, `rainy`, `cloudy`, `stormy`, and `snowy` until it is replaced or
cleared with `-128`.

`SET_ANIMATION` and `SET_EXPRESSION` accept these payloads:

| Offset | Meaning |
| ---: | --- |
| 0 | Destination animation ID |
| 1 | Optional transition token; omitted commands use `0` |
| 2 | Optional duration in 40 ms ticks; `0` selects the 200 ms default |

One-byte and existing two-byte commands remain accepted. The destination
timeline starts at frame zero. A new command received during a blend captures
the currently visible result and transitions from there.

The status payload is:

| Offset | Meaning |
| ---: | --- |
| 0 | application protocol version |
| 1 | role (`2`) |
| 2..3 | firmware major/minor |
| 4 | current animation |
| 5 | last accepted sequence |
| 6 | result: `0` OK, `1` malformed, `2` unknown command, `3` bad payload |
| 7 | brightness |
| 8 | speaking intensity |
| 9 | ESP-NOW channel |
| 10 | last activated transition token |
| 11 | transition active: `0` or `1` |
| 12 | transition progress: `0..255` |

The mouth learns the sender MAC from an incoming broadcast or unicast command,
adds it as an unencrypted peer, and returns status by unicast. A repeated
sequence from the same sender is acknowledged again without executing the
command twice.

## Driver PCB pin map

| HUB75 signal | ESP32-S3 GPIO |
| --- | ---: |
| R1 | 1 |
| G1 | 2 |
| B1 | 3 |
| R2 | 5 |
| G2 | 4 |
| B2 | 6 |
| A | 8 |
| B | 7 |
| C | 10 |
| D | 9 |
| STROBE / LAT | 11 |
| CLK | 12 |
| OE- | 13 |

GPIO3 is a boot-strapping pin. The AHCT245 input should not drive it, but
unexpected boot failures warrant checking GPIO3 during reset.

## Hardware checks

- The PCB, both SN74AHCT245 level shifters, and panel require 5 V.
- Use the matrix's separate high-current 5 V power connector.
- PCB ground, panel ground, and power-supply ground must be common.
- Connect the PCB to the matrix HUB75 input, not its output.
- This firmware assumes a conventional 64x32, 1/16-scan panel.

Do not power the LED matrix from the ESP32-S3's 3.3 V rail.

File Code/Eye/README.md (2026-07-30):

# SarcasmOS Eye Firmware

Pico SDK C++ firmware for each RP2040 eye board.

The complete Workflow-derived visual and state contract is documented in
[`EYE_STATES.md`](EYE_STATES.md).

## Animation editor

The desktop emulator and the RP2040 firmware use the same palette-indexed
240x240 animation pack:

```sh
python emulator.py
```

The preview is clipped to the GC9A01's round screen. Each animation frame
uses flat Bender-style artwork with a square pupil. Each animation stores an
independent left- and right-eye orientation toggle. Weather states replace the
eye completely with a full-screen weather symbol.

Main controls:

Hover over any button to highlight it and show an explanation of its action.

- Left/Right: select one of the 31 states.
- Up/Down: select a frame and pause playback.
- Left eye/Both eyes/Right eye buttons: choose the preview layout.
- Tab: cycle through left, both side by side, and right views.
- Flip left eye: toggle horizontal flipping for the left display.
- Flip right eye: toggle horizontal flipping for the right display.
- Space: play or pause the current animation without changing states.
- A: toggle full automatic playback and scrolling through animation states.
- E: open the current native 240x240 frame in GIMP.
- O: open every frame of the current eye/animation in GIMP.
- F: open the frame timeline editor.
- Insert/Delete: add or remove a paired animation frame.
- T: change the current animation's frame time.
- S: synchronize an existing animation edit folder.
- C: copy the current native frame to the image clipboard.
- R: reload the asset pack.

The frame timeline editor can reorder a multi-frame selection, copy entries,
repeat an effect range, reverse a selection, or append the existing sequence
in reverse as an exit. Copied and repeated entries point to the same stored
left/right sprites, so they add playback steps without duplicating bitmap
data. Its side-panel preview follows the selected row; Left/Right step through
frames, and its Play button previews the unsaved working sequence without
starting state auto-scroll. The editor also selects loop or ping-pong playback
and supports the same production and alternate asset packs.

`Repeat selection…` can either add a fixed number of shared-reference repeats
or mark one contiguous range to repeat until the controller changes animation
state. An until-end range has its own Regular/Ping-pong toggle: intro frames
before the range play once, the selected effect then repeats indefinitely, and
the next state command requests its exit. Timeline rows after the persistent
range then play once as an outro before the pending state begins. When a loop
occupies the final pose of a whole-animation ping-pong, its entry frames become
the automatic return outro. The timeline marks range rows with `↔`.
The left-side Animation actions panel lists each persistent loop. Its Delete
button removes the action without deleting frames or artwork; double-clicking
the action text opens it in edit mode so its range and loop direction can be
changed. Save the timeline to persist action edits or deletions.

Saving an emulator-exported PPM over the same file makes the emulator import
it automatically, update `assets/eye_assets.json`, regenerate
`generated/eye_assets.hpp`, and reload the preview. New exact colors occupy
free slots in the shared 16-color palette; once full, imports use the nearest
palette color. Orientation buttons update the preview immediately and save
only their two small per-animation settings; firmware assets are regenerated
during the next normal build.

Headless validation and command-line frame exchange are also available:

```sh
python emulator.py --self-test
python emulator.py --state angry --view both --gap 24 --dump angry-pair.ppm
python emulator.py --state angry --view right --dump angry-right.ppm
python asset_tool.py export happy_fake happy-left.ppm --role left --frame 2
python asset_tool.py import happy_fake happy-left.ppm --role left --frame 2
python asset_tool.py validate
python asset_tool.py compile
```

An alternate emulator-compatible pack maps animations extracted from the
external procedural ESP32 sketch onto the production pack's same 31 state IDs
and order. It can be previewed without replacing the production assets:

```sh
python emulator.py --assets "new animations/eye_assets.json" --view both
```

Alternate packs support the same frame and timeline editing, GIMP auto-import,
add/remove, timing, folder synchronization, and orientation controls as the
production pack. Changes are written only to the path passed through
`--assets`; editing an alternate pack does not regenerate the production
firmware header. Independent left/right artwork is preserved when only one
alternate-pack eye is edited.

The ready-made PNG animation set is also available as a lossless converted
31-state pack:

```sh
python emulator.py --assets "png animations/eye_assets.json" --view both
```

Its original PNG sources and reproducible converter are kept together under
`png animations/`.

`create_default_assets.py --force` recreates the initial procedural artwork
and destroys manual sprite edits. Normal CMake builds regenerate only the C++
header when the editable JSON or compiler changes.

## Build

The helper script can build, upload, and then monitor all three firmware types
for either eye:

```sh
./flash.sh --left --regular --build --upload --swd-monitor
./flash.sh --left --self-test --build --upload --swd-monitor
./flash.sh --right --demo --build --upload --swd-monitor
./flash.sh --right --demo --assets "png animations/eye_assets.json" --build --upload
./flash.sh --auto --regular --assets "png animations/eye_assets.json" --build --upload
```

`--regular` is the default and receives animation commands over I2C.
`--self-test` cycles through display patterns, while `--demo` cycles through all
31 animations and prints each animation's name and ID. Regular firmware also
reports every I2C-driven animation change. Use `--monitor` for UART or
`--swd-monitor` to stream the same messages non-intrusively over SWD using RTT;
the SWD monitor needs no serial adapter and keeps the RP2040 running.
Actions, firmware type, and the eye selector can appear in any order. The UART
monitor automatically uses the only connected `/dev/serial/by-id`,
`/dev/ttyACM`, or `/dev/ttyUSB` device. If more than one is connected, select
one with `--port /dev/ttyACM0` or set `EYE_LEFT_PORT` and `EYE_RIGHT_PORT`.
Run `./flash.sh --help` for all options and environment overrides.
`--auto` reads a role marker from current firmware over SWD, falling back to
the active I2C slave address for older regular/demo images. It reports the
detected eye before selecting the build directory and never guesses when the
probe is inconclusive.

Every activated animation starts at frame zero on its own local clock. A
request for another state becomes the current animation's end signal. Regular
playback completes its forward pass, whole-animation ping-pong completes its
return to frame zero, and a persistent range loop runs its stored outro before
holding its final legal exit frame. At that barrier the Eye reports READY and
waits for a matching `CMD_SYNC`; it never activates the pending state early. If
a range occupies the final frames and the animation itself is ping-pong,
firmware automatically returns through the entry frames. Therefore demo states
remain active for at least three seconds and may take slightly longer while
their graceful exit finishes. Demo mode commits its own READY transitions;
regular I2C mode waits for Brain's paired commit.

Animation and expression commands accept either the legacy one-byte payload
`{animation}` or the synchronized payload
`{animation, transition_token, mouth_duration_ticks}`. The eye ignores the
mouth-duration byte, keeps playing the current animation through its legal
exit, and associates the token with the destination only when a matching commit
starts it. Repeating an already queued animation/token pair does not restart
playback; a newer queued request replaces the older destination and clears the
old READY/commit state. Requesting the active animation with a new token creates
an immediately READY restart so two drifting Eyes can be resynchronized.

`CMD_SYNC` is the four-byte commit payload
`{transition_token, delay_ms_low, delay_ms_high, flags}`. Flags must be zero and
the little-endian delay must be 10–250 ms; Brain uses 50 ms. The deadline is
based on the local I2C STOP timestamp. Both Eyes therefore start frame zero at
their corresponding future deadlines even if command parsing is delayed. A
READY Eye without a valid commit holds the exit pose and reports an error after
five seconds. On every committed activation the onboard LED inverts for 10 ms,
providing a logic-analyzer timing point over the normal heartbeat.

Eye protocol version `0x02` returns a 13-byte status response:

| Offset | Field |
| ---: | --- |
| 0 | protocol version |
| 1 | left/right device role |
| 2–3 | firmware major/minor |
| 4 | active animation |
| 5 | last accepted command sequence |
| 6 | last error |
| 7 | brightness |
| 8 | pending animation, or `0xFF` |
| 9 | active transition token |
| 10 | pending transition token, or `0` |
| 11 | playback flags: pending (bit 0), exiting (bit 1), activated/no pending (bit 2), READY (bit 3) |
| 12 | current local frame |

The controller should treat an eye as complete only when one full response has
the requested animation and token active, no pending animation/flag, and no
error. Command sequence acknowledgement alone means only that the request was
accepted. Protocol `0x01` controllers must be updated before using this
firmware because they read only the former eight-byte response.

Use `--assets PATH` to compile regular or demo firmware with another compatible
asset pack. The generated header stays inside that firmware's build directory,
so building an alternate pack does not overwrite `generated/eye_assets.hpp` or
the production asset source. Upload-only commands verify that the selected pack
path matches the image configuration and ask for a rebuild if it does not.

All three firmware modes use the same 180-degree display transform. Per-eye
orientation comes exclusively from each animation's `flip_left` and
`flip_right` emulator settings, so the right display does not reverse the
generated artwork a second time.

The equivalent manual build commands are below.

Left eye:

```sh
cmake -S . -B build-left -DDEVICE_ROLE=0 -DI2C_ADDRESS=0x30
cmake --build build-left
```

Right eye:

```sh
cmake -S . -B build-right -DDEVICE_ROLE=1 -DI2C_ADDRESS=0x31
cmake --build build-right
```

Display test:

```sh
cmake -S . -B build-test
cmake --build build-test --target sarcasmos_eye_display_test
```

The display test cycles every three seconds through black, white, red, green,
blue, vertical and horizontal color bars, a checkerboard, an alignment screen,
a grayscale gradient, and a two-axis RGB gradient.

Animation autoplay test:

```sh
cmake -S . -B build-animation-test \
  -DANIMATION_AUTOPLAY=ON \
  -DDEVICE_ROLE=0 \
  -DI2C_ADDRESS=0x30
cmake --build build-animation-test --target sarcasmos_eye
```

This is the real eye firmware with automatic animation selection enabled. It
shows each of the 31 animation states for three seconds, completing a cycle in
93 seconds. Normal builds leave autoplay disabled and continue to select
animations through I2C.

Host playback and transition-token tests:

```sh
c++ -std=c++17 -Wall -Wextra -Werror -Iinclude \
  tests/animation_playback_test.cpp -o /tmp/eye-animation-playback-test
/tmp/eye-animation-playback-test
```

## Upload with J-LinkOB

The old J-LinkOB firmware cannot configure the RP2040 through J-Link Commander,
but OpenOCD can access core 0 directly. From this directory, upload the display
test with:

```sh
OPENOCD_ROOT=/home/pegoku/.espressif/tools/openocd-esp32/v0.12.0-esp32-20260424/openocd-esp32
EYE_IMAGE=build-test/sarcasmos_eye_display_test.elf
"${OPENOCD_ROOT}/bin/openocd" \
  -s "${OPENOCD_ROOT}/share/openocd/scripts" \
  -f interface/jlink.cfg \
  -c "adapter speed 100" \
  -c "set USE_CORE 0" \
  -f target/rp2040.cfg \
  -c "program ${EYE_IMAGE} verify reset exit"
```

Use `EYE_IMAGE=build-left/sarcasmos_eye.elf` or
`EYE_IMAGE=build-right/sarcasmos_eye.elf` to upload the normal left- or
right-eye firmware. Use
`EYE_IMAGE=build-animation-test/sarcasmos_eye.elf` for the animation autoplay
test. OpenOCD verifies the flash and resets the RP2040; the RUN and BOOT buttons
are not required.

## Notes

- I2C slave uses `GPIO4`/`GPIO5`.
- Display SPI uses `GPIO17`/`GPIO18`/`GPIO19` plus `DC=GPIO20`, `RST=GPIO21`, `BL=GPIO22`.
- The round 240x240 RGB565 display uses a GC9A01A controller.

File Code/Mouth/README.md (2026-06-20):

# SarcasmOS Mouth Firmware

Pico SDK C++ firmware for the RP2040 HUB75/HUB75E mouth board.

## Build

```sh
cmake -S . -B build -DI2C_ADDRESS=0x32
cmake --build build
```

## Notes

- I2C slave uses `GPIO4`/`GPIO5`.
- Matrix pins match the PCB docs: RGB data on `GPIO6`-`GPIO11`, `E/A/B/C/D` on `GPIO12`-`GPIO16`, `CLK=GPIO17`, `LAT=GPIO18`, `OE=GPIO19`.
- Output defaults to a 128x64, 1/32-scan HUB75E panel with a 4-bit-per-channel scan loop.
- `SET_PARAM` with key `1` updates speaking mouth intensity.

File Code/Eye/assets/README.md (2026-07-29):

# Eye animation assets

`eye_assets.json` is the editable source of truth for the emulator and RP2040
firmware. It contains paired 240x240 palette-indexed artwork for both eyes, one
animation entry for every protocol state, frame timing, independent left/right
orientation toggles, and loop or ping-pong playback metadata.

Use `../emulator.py` for visual editing. The generated
`../generated/eye_assets.hpp` file is deterministic firmware data and must not
be edited by hand.

In the emulator, select a state and frame, use the Left/Both/Right buttons or
Tab to choose the view, then press `E` to edit one frame or `O` to edit the
complete animation in GIMP. In the combined view, editing uses the left eye.
Overwriting an exported PPM automatically imports it. Whole-animation folders
use names such as `angry-left-frame-01.ppm`; adding, deleting, or renumbering
these files changes the animation sequence and regenerates the opposite eye
as its horizontal mirror.

Use `Flip left eye` and `Flip right eye` to toggle each displayed orientation
independently. This is useful for directional gaze and other states that
should not use the default mirrored presentation. The buttons change the
emulator immediately and save the setting without compiling; the next normal
firmware build applies it to the generated frame pairs.

The pack supports `loop` and `ping_pong` playback. Frame timing is stored per
animation. Adding or removing a frame always changes the paired sequence, so
the two eye boards remain synchronized.

Press `F` to edit the animation's frame timeline. Timeline rows are references
to stored sprite pairs: copying a row or repeating a selected effect range does
not copy its bitmap data. Rows can be reordered, reversed, deleted, or expanded
with a reverse exit, and the editor can switch the animation between loop and
ping-pong playback. The preview side panel shows the selected frame, steps with
Left/Right, and plays the unsaved working timeline independently from emulator
auto-scroll. Saving rewrites only the selected asset pack.

The repeat dialog can also store an optional contiguous `loop_range`. Frames
before it form a one-shot intro; the range then repeats in regular or ping-pong
mode until a new animation state is requested. That request acts as an end
signal: the range completes cleanly, stored frames after it play as the outro,
and only then does firmware activate the pending state. A final-pose range in a
whole-animation ping-pong automatically returns through the intro frames. This
range is compiled into firmware rather than expanded into duplicate bitmaps.
Persistent loops appear in the timeline editor's Animation actions panel.
Double-click an action to edit it, or use the row's Delete button to remove the
loop metadata while preserving every frame and sprite reference.

`../create_default_assets.py --force` recreates the original procedural
Bender-style artwork. It overwrites manual edits, so it is intended only as a
reset/bootstrap tool.

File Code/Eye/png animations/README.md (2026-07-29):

# Ready-made PNG animation pack

This directory contains the 240x240 PNG animations imported from
`/home/pegoku/Downloads/eyes animations` and converted into the same
palette-indexed `sarcasmos-eye-assets` JSON format used by the desktop emulator
and firmware asset compiler.

The source images are already fully opaque, round-screen-safe, and share exactly
16 colors. Conversion is lossless: no resizing, color quantization, or generated
in-between frames are applied. Each PNG is treated as a native left-eye frame;
the paired right-eye frame is stored as its horizontal mirror, matching the
production asset contract.

## View and edit

From the `Eye` directory:

```sh
python emulator.py --assets "png animations/eye_assets.json" --view both
```

The alternate pack supports the emulator's normal GIMP auto-import, frame
insertion/removal, timing, folder synchronization, and orientation controls.
Firmware starts every selected PNG animation at its first frame. A later state
request is queued until the current animation finishes its forward outro or
ping-pong return; persistent final-pose loops therefore return smoothly through
their entry frames before animations such as `left` and `right` switch.

## Rebuild

The original PNGs are preserved under `source/`. Rebuild the JSON with:

```sh
python "png animations/build_png_pack.py"
```

This deliberately replaces manual edits made to `eye_assets.json`.

## Standard-name mapping

The resulting pack uses the exact 31 production animation names, IDs, and
ordering. Supplied folder/file typos are normalized automatically:
`angy` → `angry`, `boared` → `bored`, `rainny` → `rainy`, `surprisde` →
`surprised`, and `claudy` → `cloudy`.

Five standard states have no dedicated source folder and use these fallbacks:

| Standard state | PNG source | Reason |
|---|---|---|
| `listening` | `thinking` | Closest available attentive motion |
| `thinking_audio` | `thinking` | No audio-specific PNG sequence |
| `thinking_long` | `thinking` | Same artwork with a slower frame delay |
| `asleep` | `blink/blink4.png` | Last visible closed-eye frame; `blink5` is blank |
| `center` | `neutral-central/neutral.png` | Centered neutral pose |

The supplied `blink` sequence is not a standard protocol animation ID, so only
its closed frame is used for `asleep`.

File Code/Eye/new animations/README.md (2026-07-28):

# Procedural bot animations

This folder extracts the procedural renderer from `BotAnimator_ESP32.ino` into
portable C++17 and includes a generated bitmap pack that the repository's
existing `emulator.py` can display. The renderer itself contains no hardcoded
animation bitmaps; `eye_assets.json` is a sampled, regenerable preview/export
of its RGB565 drawing primitives.

The renderer targets one 240x240 round display at a time. Call it with the same
timestamp for the left and right boards to keep the pair synchronized.

The current extraction comes from
`ESP32_Bot_Animations_Code(1)/esp32/BotAnimator_ESP32.ino`, SHA-256
`79bee8c3205b0529782df7d4fd7d64983247466becd68e4a8155f625e0e9dc20`.
Compared with the previous supplied sketch, this revision adds pulsing ringed
Play/Pause/Stop icons and renders them identically on both displays.

## Extracted catalog

The source sketch exposes 44 selectable variants:

- Eyes (13): idle, look, alert, angry, surprised, happy, suspicious, confused,
  dizzy, listening, glitch, sleep, off.
- Music (7): play, pause, stop, previous/next pair, volume pair, equalizer,
  wave.
- Clock (7): digital, analog, seconds, minimal, stopwatch, timer, alarm.
- Weather (8): sun, clouds, rain, storm, snow, wind, fog, night.
- System (9): power on, power off, update, install, Wi-Fi, battery, scan, OK,
  error.

This is a faithful extraction, including the sketch's shared fallback artwork:
digital/analog/seconds/minimal currently render the same clock layout;
clouds/rain/storm/snow share one cloud shape; and update/install/scan share the
same scan/progress screen. The incoming README mentions blink, but the supplied
`.ino` has no `Blink` enum or blink renderer, so no nonexistent animation was
invented here.

## Files

- `procedural_animations.hpp` is the stable public API and complete state list.
- `procedural_animations.cpp` contains all extracted animation behavior.
- `eye_assets.json` contains the rendered, palette-indexed 240x240 frames in
  the same `sarcasmos-eye-assets` format used by the current emulator. It uses
  the production pack's exact 31 IDs, names, and order.
- `MAPPING.md` records how each production state maps to a procedural source.
- `bitmap_exporter.cpp` rasterizes the real extracted C++ renderer.
- `build_bitmap_pack.py` rebuilds `eye_assets.json` from that rasterizer.
- `adapters/tft_espi_canvas.hpp` connects it to the original Arduino library.
- `tests/smoke_test.cpp` renders both sides of every selectable variant through
  a fake drawing backend.

## View the animations

Run this from the `Eye` directory:

```sh
python emulator.py --assets "new animations/eye_assets.json" --view both
```

Use Left/Right to move through all 31 mapped animations, Up/Down to step frames,
and Space to play or pause. Frame editing, GIMP auto-import, add/remove, timing,
folder synchronization, and orientation controls write directly to this
alternate JSON without changing the production pack or firmware header.

Edits to one eye preserve the other eye's independent artwork. Running
`build_bitmap_pack.py` again deliberately regenerates this file and replaces
manual edits, so copy an edited pack first if the procedural source is also
being changed.

Headless preview and validation work too:

```sh
python emulator.py \
  --assets "new animations/eye_assets.json" \
  --state eye-angry --view both --dump /tmp/eye-angry.ppm
python emulator.py --assets "new animations/eye_assets.json" --self-test
```

Regenerate every bitmap after changing the procedural C++:

```sh
python "new animations/build_bitmap_pack.py"
```

The procedural source still contains all 44 original variants. Generate a
temporary unmapped pack containing all of them with `--all`; see `MAPPING.md`.

## Use later in firmware

Copy this folder into the firmware project and implement `Canvas` using the
display driver's primitive calls. The included adapter already does this for
TFT_eSPI:

```cpp
#include "new animations/adapters/tft_espi_canvas.hpp"

TFT_eSPI tft;
bot_animations::TftEsPiCanvas canvas(tft);
bot_animations::Renderer renderer(canvas);
bot_animations::State animation;

void loop() {
  static uint32_t lastFrameMs = 0;
  const uint32_t nowMs = millis();
  if (nowMs - lastFrameMs < bot_animations::kFrameIntervalMs) return;
  lastFrameMs = nowMs;

  animation.screen = bot_animations::ScreenMode::Eyes;
  animation.eye = bot_animations::EyeState::Angry;

  selectLeftDisplay();
  renderer.render(animation, bot_animations::Side::Left, nowMs);
  selectRightDisplay();
  renderer.render(animation, bot_animations::Side::Right, nowMs);
}
```

When changing a time-relative mode such as power on/off, save its start time:

```cpp
animation.screen = bot_animations::ScreenMode::System;
animation.system = bot_animations::SystemMode::PowerOn;
animation.modeStartedMs = millis();
```

For this repository's RP2040/GC9A01 firmware, keep the public renderer intact
and add a `Canvas` adapter beside `gc9a01.cpp`. That is the only hardware-specific
piece needed. Text rendering and arcs are deliberately part of the adapter
contract because the current low-level driver only streams pixels and does not
yet provide graphics primitives.

## Host validation

From this directory:

```sh
c++ -std=c++17 -Wall -Wextra -Werror \
  procedural_animations.cpp tests/smoke_test.cpp -o /tmp/bot-animation-smoke
/tmp/bot-animation-smoke
```

The original memory rule still applies to firmware: use the procedural renderer
to store zero full-screen frames when possible. The JSON bitmap pack exists for
the desktop emulator and asset interchange. It can also be compiled by the
existing RLE compiler. Its state count and ordering already match the current
firmware protocol; replacing production artwork remains a separate deliberate
integration step.

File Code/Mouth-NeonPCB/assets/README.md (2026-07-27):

# Mouth animation assets

`mouth_assets.json` is the single source of truth for both the desktop
emulator and ESP32 firmware. Artwork and animation timing must be changed here,
not in `mouth_display.cpp`, `emulator.py`, or the generated C++ header.

Live weather temperature text is a dynamic black overlay and is intentionally
not baked into these sprites. Editing a weather frame in GIMP therefore edits
only the underlying animation; firmware and emulator add the current `°C`
value after rendering the selected frame. Its small pixel glyphs live in
`temperature_font.json`, which is also shared by both renderers.

The pack contains:

- a shared palette of up to 16 RGB colors;
- 64x32 sprites stored as 32 rows of hexadecimal palette indices;
- one animation entry for every protocol state;
- ordered frame references, frame duration, and a playback mode.

Playback modes are:

- `loop`: advance through frames and wrap;
- `ping_pong`: advance to the last frame and reverse;
- `intensity`: use speaking intensity to scale a triangular frame sequence.

## Visual editing

Run `../emulator.py`, pause on a state with Left or Right, and use:

1. Pause playback with Space. Use Up/Down to select an exact frame.
2. **Open frame in GIMP** (`e`) to export and open the current native frame,
   or **Open animation in GIMP** (`o`) to open every frame for the state.
3. Edit without resizing the 64x32 canvas. Disable interpolation when scaling
   the view; individual pixels are intentional.
4. Overwrite the opened PPM from GIMP. The emulator detects the overwrite,
   preserves new colors in available palette slots, updates this pack,
   regenerates the firmware header, and reloads the preview automatically.
   **Import saved edit** (`i`) remains available as a manual refresh.

When an animation is opened with `o`, its files form an editable, one-based
sequence:

- `watch-frame-01.ppm` is the first frame and `watch-frame-09.ppm` is the
  ninth.
- Saving a new `watch-frame-10.ppm` adds a tenth frame.
- A number beyond the next position is accepted and compacted. For example,
  adding `watch-frame-12.ppm` to a nine-frame sequence renames it to
  `watch-frame-10.ppm`.
- Deleting frame 7 removes it; old frames 8 and 9 are renamed to 7 and 8.
- At least one frame must remain. An empty animation is rejected.

The animation JSON, sprite records, generated header, displayed frame count,
and temporary PPM filenames update together after the files remain stable for
250 ms. Sequence editing is available in the folder opened by **Open
animation**, not the separate single-frame edit folder.

The emulator also provides direct **Add frame after current** and **Remove
current frame** buttons:

- adding while viewing frame 2 creates a separate copy as frame 3;
- the old frame 3 becomes frame 4, and every later frame shifts likewise;
- the new copy is selected immediately and can be edited independently;
- removing a frame shifts every later frame backward and selects the frame
  that moved into its position, or the new last frame;
- the final remaining frame cannot be removed.

`Insert` and `Delete` are keyboard shortcuts for these buttons. Structural
changes invalidate any older GIMP edit session for that animation; reopen it
with `o` if continued multi-frame editing is needed.

Use **Set frame time** (`T`) to change the current animation's delay between
frames. The dialog accepts `1..65535` milliseconds and updates the
animation's `frame_ms` value, emulator timing, and generated firmware header
without changing any frame artwork.

Use **Sync folder** (`S`) after restarting the emulator, or whenever an
existing `/tmp/sarcasmos-mouth-edit/animations/<state>` folder is not attached
to the current session. It imports all correctly numbered PPMs without first
exporting over them, reloads the preview, and resumes automatic watching of
that folder. By contrast, **Open animation in GIMP** exports the current asset
frames before opening them, so it should not be used to recover newer
unimported files.

**Copy frame** (`c`) copies a 64x32 PNG for sharing or attaching to a request.

## Command-line editing

```sh
../asset_tool.py export speaking speaking-frame-0.ppm --frame 0
../asset_tool.py import speaking speaking-frame-0.ppm --frame 0
../asset_tool.py validate
../asset_tool.py compile
```

Import accepts binary P6 PPM images at exactly 64x32. Existing full-brightness
and emulator `64/255` colors map back to their original palette entries. A new
exact RGB color is added to the shared palette while one of its 16 slots is
free; only additional colors after the palette is full are mapped to the
nearest entry.

`generated/mouth_assets.hpp` and `generated/temperature_font.hpp` are
deterministic build artifacts. PlatformIO regenerates them when their source
asset or compiler is newer. Never edit either generated header by hand.

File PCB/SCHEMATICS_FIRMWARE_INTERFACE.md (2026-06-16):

# SarcasmOS PCB Schematics and Firmware Interface

This document summarizes the three KiCad PCB designs in this repository from a firmware point of view. It is intended for someone who does not have the PCB files open, but needs to understand what is connected to what in order to write firmware. The planned software architecture is documented separately in `FIRMWARE_PLAN.md`.

Source schematics checked:

- `PCB/brain/brain.kicad_sch`
- `PCB/eye/eye.kicad_sch`
- `PCB/mouth/mouth.kicad_sch`

## System Overview

The physical PCB set is split into three board designs, with four boards expected in the assembled robot:

- `brain`: Main controller board. It contains an ESP32-S3 module, USB-C/power management, battery charger/fuel gauge, Ethernet controller, audio amplifier/microphone interface, stepper motor driver, power regulators, and connectors to the other boards.
- `eye`: RP2040-based display board. The robot uses two copies of this PCB, one for each eye. Each eye drives an `LH128` 12-pin display module and exposes I2C, UART/SWD/debug, and display breakout connectors.
- `mouth`: RP2040-based HUB75-style LED matrix interface board. It drives a 16-pin RGB matrix connector through 74AHCT244 level shifters and exposes I2C plus UART/SWD/debug.

The expected firmware architecture is:

- ESP32-S3 on `brain` is the main controller.
- Two RP2040 eye boards are display coprocessors, reachable from the brain over I2C with different slave addresses.
- RP2040 on `mouth` is a LED matrix coprocessor, reachable from the brain over I2C.
- All runtime display control commands from the brain to the two eyes and the mouth are expected to use I2C.
- The brain runs the high-level voice-assistant logic: web/API control, audio playback/capture, networking, animation selection, and I2C commands to the display coprocessors.
- Optional UART/SWD connectors on `eye` and `mouth` are for firmware loading/debugging, not the primary brain-to-board runtime link unless firmware chooses to use them externally.

## Inter-Board Connections

### Brain to Eye or Mouth I2C/Power Bus

The brain has four identical JST-XH 4-pin connectors: `J2`, `J4`, `J5`, and `J6`. Each connector carries the same bus:

| Brain connector pin | Net | Function |
|---:|---|---|
| 1 | `+5V` | 5 V power output from brain |
| 2 | `SDA` | I2C data |
| 3 | `SCL` | I2C clock |
| 4 | `GND` | Ground |

The two `eye` boards `J2` and the `mouth` board `J2` have the same pinout:

| Eye/Mouth `J2` pin | Net | Function |
|---:|---|---|
| 1 | `+5V` | 5 V input |
| 2 | `SDA` | I2C data to RP2040 GPIO4 |
| 3 | `SCL` | I2C clock to RP2040 GPIO5 |
| 4 | `GND` | Ground |

The schematic does not assign a specific brain connector to left eye, right eye, or mouth; `J2`, `J4`, `J5`, and `J6` are electrically interchangeable I2C/power ports. A typical assembly would use three of the four connectors: one for left eye, one for right eye, and one for mouth.

### Runtime I2C Devices

The firmware should treat the display boards as separate I2C slaves on the same bus:

| Device | Board design | Connector | Role | I2C address |
|---|---|---|---|---|
| Left eye | `eye` | `J2` | Eye display coprocessor | Firmware-assigned, unique |
| Right eye | `eye` | `J2` | Eye display coprocessor | Firmware-assigned, unique |
| Mouth | `mouth` | `J2` | Mouth/LED matrix coprocessor | Firmware-assigned, unique |

The schematic does not include address-selection hardware for the eye boards, so left/right identity must be handled in firmware, flash configuration, build configuration, or another external provisioning step.

### I2C Electrical Details

On the brain board, the I2C bus has pull-ups to `+3.3V`:

| Signal | ESP32-S3 pin | Pull-up |
|---|---|---|
| `SDA` | `IO8` | `R12`, 4.7 kOhm to `+3.3V` |
| `SCL` | `IO9` | `R13`, 4.7 kOhm to `+3.3V` |

The I2C bus also connects to the brain's power-management ICs:

| Device | SDA | SCL | Notes |
|---|---|---|---|
| `U9` BQ25792 charger | pin 15 | pin 14 | Charger control/status |
| `U10` MAX17049 fuel gauge | pin 8 | pin 7 | Battery monitoring |
| External boards | connector pin 2 | connector pin 3 | Two eyes and mouth RP2040 I2C slaves |

Because pull-ups are on the brain, the eye and mouth firmware should normally configure `SDA`/`SCL` as open-drain I2C pins and should not enable strong pull-ups unless required.

## Brain PCB

### Main ICs

| Ref | Part | Firmware relevance |
|---|---|---|
| `U1` | ESP32-S3-WROOM-1 | Main MCU |
| `U2` | TMC2209-LA | Stepper motor driver |
| `U3` | W5500 | SPI Ethernet controller |
| `U4` | MAX98357A | I2S DAC/class-D speaker amplifier |
| `MK1` | ICS-43434 | I2S digital microphone |
| `U9` | BQ25792 | I2C battery charger/power-path controller |
| `U10` | MAX17049G+T10 | I2C battery fuel gauge |
| `U11` | AP64501SP-13 | High-power 5 V regulator, ESP32 enabled |
| `U12` | AP63205WU | 5 V regulator, ESP32 enabled |
| `U14` | AP63203WU | 3.3 V regulator |

### ESP32-S3 Firmware Pin Map

| ESP32-S3 signal | Module pad | Net | Connected to | Firmware use |
|---|---:|---|---|---|
| `EN` | 3 | `EN` | Reset pushbutton `EN1`, RC reset circuit | ESP32 enable/reset |
| `IO0` | 27 | `BOOT` | Boot pushbutton `BOOT1`, 10 kOhm pull-up | Bootloader strap button |
| `IO1` | 39 | `5V_EN` | `U12` enable | Enable/disable 5 V regulator |
| `IO2` | 38 | `5VHP_EN` | `U11` enable | Enable/disable high-power 5 V rail |
| `IO4` | 4 | `RX1` | `J11` pin 2 | UART1 RX or general I/O |
| `IO5` | 5 | `TX1` | `J11` pin 3 | UART1 TX or general I/O |
| `IO6` | 6 | `CE` | `U9` BQ25792 pin 13 | Charger CE control |
| `IO7` | 7 | `BQINT` | `U9` BQ25792 pin 21, `TP6` | Charger interrupt input |
| `IO8` | 12 | `SDA` | I2C bus, `U9`, `U10`, `J2/J4/J5/J6` | I2C SDA |
| `IO9` | 17 | `SCL` | I2C bus, `U9`, `U10`, `J2/J4/J5/J6` | I2C SCL |
| `IO10` | 18 | `EthCS` | `U3` W5500 `SCS`, `J7` pin 5 | Ethernet SPI chip-select |
| `IO11` | 19 | `MOSI` | `U3` W5500 `MOSI`, `J7` pin 3 | Ethernet SPI MOSI |
| `IO12` | 20 | `SCLK` | `U3` W5500 `SCLK`, `J7` pin 4 | Ethernet SPI clock |
| `IO13` | 21 | `MISO` | `U3` W5500 `MISO`, `J8` pin 6 | Ethernet SPI MISO |
| `IO14` | 22 | `INTn` | `U3` W5500 interrupt, `J7` pin 6 | Ethernet interrupt input |
| `IO15` | 8 | `RSTn` | `U3` W5500 reset, `J8` pin 5 | Ethernet reset output |
| `IO16` | 9 | `STEP` | `U2` TMC2209 `STEP`, `J10` pin 5 | Stepper step pulse |
| `IO17` | 10 | `DIR` | `U2` TMC2209 `DIR`, `J10` pin 6 | Stepper direction |
| `IO18` | 11 | `TmcEN` | `U2` TMC2209 `~EN`, `J10` pin 10 | Stepper driver enable, active low |
| `IO21` | 23 | `UART` | `U2` TMC2209 `PDN_UART`, `J10` pin 7 | TMC2209 single-wire UART |
| `IO38` | 31 | `DIAG` | `U2` TMC2209 `DIAG`, `J10` pin 11 | Stepper diagnostic input |
| `IO39` | 32 | `BCLK` | `U4` MAX98357A `BCLK`, `MK1` clock, `J13` pin 4 | I2S bit clock |
| `IO40` | 33 | `LRCLK` | `U4` MAX98357A `LRCLK`, `MK1` WS, `J13` pin 2 | I2S word select |
| `IO41` | 34 | `DIN` | `U4` MAX98357A `DIN` | I2S speaker data out |
| `IO42` | 35 | `ALRT` | `U10` MAX17049 alert | Battery/fuel-gauge alert input |
| `IO47` | 24 | `MicDATA` | `MK1` ICS-43434 data, `J13` pin 3 | I2S microphone data in |
| `IO48` | 25 | `Net-(D1-A)` | Status LED `D1` anode | User/status LED output |
| `RXD0` | 36 | `RX0` | `J14` pin 2 | ESP32 UART0 RX |
| `TXD0` | 37 | `TX0` | `J14` pin 1 | ESP32 UART0 TX |
| `USB_D-` | 13 | `D-` | USB-C through 22 Ohm resistor/ESD | Native USB D- |
| `USB_D+` | 14 | `D+` | USB-C through 22 Ohm resistor/ESD | Native USB D+ |

Unconnected ESP32-S3 module pins in the schematic: `IO3`, `IO35`, `IO36`, `IO37`, `IO45`, and `IO46`.

### Brain Connectors

#### Power Input/Output

| Connector | Pin | Net | Description |
|---|---:|---|---|
| `J1` screw terminal | 1 | `5VHP` | High-power 5 V rail output/input node |
| `J1` screw terminal | 2 | `GND` | Ground |
| `J12` battery JST | 1 | `Net-(BT2--)` | Battery stack negative/protection node |
| `J12` battery JST | 2 | `Net-(BT1--)` | Battery midpoint / BT1 negative / BT2 positive |
| `J12` battery JST | 3 | `+BATT` | Battery positive |

`USB1` is a USB-C connector. `VBUS` goes through fuse `F1` to `VUSB`, then into the charger/power path. `D+` and `D-` connect to the ESP32-S3 native USB pins through 22 Ohm series resistors and ESD protection.

#### I2C/Power Expansion Connectors

`J2`, `J4`, `J5`, and `J6` are identical 4-pin JST-XH connectors:

| Pin | Net | Description |
|---:|---|---|
| 1 | `+5V` | 5 V power |
| 2 | `SDA` | I2C data |
| 3 | `SCL` | I2C clock |
| 4 | `GND` | Ground |

#### Ethernet Debug/Breakout Headers

`J7` exposes Ethernet SPI-side signals:

| `J7` pin | Net | Function |
|---:|---|---|
| 1 | `GND` | Ground |
| 2 | `GND` | Ground |
| 3 | `MOSI` | SPI MOSI |
| 4 | `SCLK` | SPI clock |
| 5 | `EthCS` | W5500 chip select |
| 6 | `INTn` | W5500 interrupt |

`J8` exposes additional Ethernet-side/debug signals:

| `J8` pin | Net | Function |
|---:|---|---|
| 1 | `GND` | Ground |
| 2 | `+3.3V` | 3.3 V |
| 3 | `+3.3V` | 3.3 V |
| 4 | unconnected | No connection |
| 5 | `RSTn` | W5500 reset |
| 6 | `MISO` | SPI MISO |

#### Stepper Motor/TMC2209 Connectors

`J9` is the 4-pin motor coil connector:

| `J9` pin | Net | TMC2209 output |
|---:|---|---|
| 1 | `OA2` | Coil A output 2 |
| 2 | `OA1` | Coil A output 1 |
| 3 | `OB1` | Coil B output 1 |
| 4 | `OB2` | Coil B output 2 |

`J10` is a 12-pin TMC2209 control/power header:

| `J10` pin | Net | Description |
|---:|---|---|
| 1 | `VS` | Motor supply |
| 2 | `GND` | Ground |
| 3 | `GND` | Ground |
| 4 | `+3.3V` | Logic supply |
| 5 | `STEP` | Step input from ESP32 `IO16` |
| 6 | `DIR` | Direction input from ESP32 `IO17` |
| 7 | `UART` | TMC2209 UART from ESP32 `IO21` |
| 8 | `MS1` | Microstep/address pin |
| 9 | `MS2` | Microstep/address pin |
| 10 | `TmcEN` | Enable, active low, from ESP32 `IO18` |
| 11 | `DIAG` | Diagnostic output to ESP32 `IO38` |
| 12 | `INDEX` | TMC2209 index output |

### Brain Peripheral Details

#### W5500 Ethernet

The W5500 is connected to the ESP32-S3 by SPI:

| W5500 signal | Net | ESP32-S3 pin |
|---|---|---|
| `SCS` | `EthCS` | `IO10` |
| `SCLK` | `SCLK` | `IO12` |
| `MOSI` | `MOSI` | `IO11` |
| `MISO` | `MISO` | `IO13` |
| `INT` | `INTn` | `IO14` |
| `RST` | `RSTn` | `IO15` |

The W5500 connects to RJ45 MagJack `J3`. LED outputs are wired to RJ45 LED pins through resistors: `LINKLED` and `ACTLED`. The Ethernet PHY has a 25 MHz crystal.

#### Audio

The speaker amplifier is a MAX98357A on I2S:

| Signal | Net | ESP32-S3 pin | Also connected to |
|---|---|---|---|
| Bit clock | `BCLK` | `IO39` | MAX98357A pin 16, microphone pin 4, `J13` pin 4 |
| Word select | `LRCLK` | `IO40` | MAX98357A pin 14, microphone pin 1, `J13` pin 2 |
| Speaker data out | `DIN` | `IO41` | MAX98357A pin 1 |
| Microphone data in | `MicDATA` | `IO47` | ICS-43434 pin 6, `J13` pin 3 |

MAX98357A outputs go through ferrite beads to speaker `LS1`:

| MAX98357A pin | Net | Speaker side |
|---|---|---|
| `OUTP` pin 9 | `Net-(U4-OUTP)` | `LS1` pin 1 through `FB1` |
| `OUTN` pin 10 | `Net-(U4-OUTN)` | `LS1` pin 2 through `FB2` |

`J13` is a 5-pin audio/microphone header:

| `J13` pin | Net | Function |
|---:|---|---|
| 1 | `+3.3V` | 3.3 V power |
| 2 | `LRCLK` | I2S word select |
| 3 | `MicDATA` | I2S microphone data |
| 4 | `BCLK` | I2S bit clock |
| 5 | `GND` | Ground |

#### Power Management

The BQ25792 charger and MAX17049 fuel gauge share the brain I2C bus.

| Device signal | Net | ESP32-S3 pin | Firmware meaning |
|---|---|---|---|
| BQ25792 `SDA` | `SDA` | `IO8` | I2C data |
| BQ25792 `SCL` | `SCL` | `IO9` | I2C clock |
| BQ25792 `CE` | `CE` | `IO6` | Charger enable/control |
| BQ25792 `INT` | `BQINT` | `IO7` | Charger interrupt |
| MAX17049 `SDA` | `SDA` | `IO8` | I2C data |
| MAX17049 `SCL` | `SCL` | `IO9` | I2C clock |
| MAX17049 `ALRT` | `ALRT` | `IO42` | Fuel-gauge alert |

The ESP32 controls two 5 V regulators:

| Rail/control | Net | ESP32-S3 pin | Target IC |
|---|---|---|---|
| 5 V enable | `5V_EN` | `IO1` | `U12` AP63205WU enable |
| High-power 5 V enable | `5VHP_EN` | `IO2` | `U11` AP64501SP-13 enable |

## Eye PCB

### Main ICs

| Ref | Part | Firmware relevance |
|---|---|---|
| `U1` | RP2040 | Eye/display MCU |
| `U2` | W25Q32JVSS | External QSPI flash for RP2040 |
| `U3` | AP2112K-3.3 | 3.3 V regulator from 5 V input |
| `J1` | LH128 | Display connector/module |
| `Q1` | AO3400A | Backlight low-side switch |

### RP2040 Firmware Pin Map

| RP2040 GPIO/signal | Package pin | Net | Connected to | Firmware use |
|---|---:|---|---|---|
| `GPIO0` | 2 | `TX` | `J3` pin 7 | UART TX/debug |
| `GPIO1` | 3 | `RX` | `J3` pin 8 | UART RX/debug |
| `GPIO2` | 4 | `Net-(D1-A)` | LED `D1` anode | User/status LED |
| `GPIO4` | 6 | `SDA` | `J2` pin 2 | I2C SDA to brain |
| `GPIO5` | 7 | `SCL` | `J2` pin 3 | I2C SCL to brain |
| `GPIO6` | 8 | `Net-(U1-GPIO6)` | Test point `G6` | Test point / spare I/O |
| `GPIO7` | 9 | `Net-(U1-GPIO7)` | Test point `G7` | Test point / spare I/O |
| `GPIO8` | 11 | `Net-(U1-GPIO8)` | Test point `G8` | Test point / spare I/O |
| `GPIO9` | 12 | `Net-(U1-GPIO9)` | Test point `G9` | Test point / spare I/O |
| `GPIO10` | 13 | `Net-(U1-GPIO10)` | Test point `G10` | Test point / spare I/O |
| `GPIO11` | 14 | `Net-(U1-GPIO11)` | Test point `G11` | Test point / spare I/O |
| `GPIO12` | 15 | `Net-(U1-GPIO12)` | Test point `G12` | Test point / spare I/O |
| `GPIO13` | 16 | `Net-(U1-GPIO13)` | Test point `G13` | Test point / spare I/O |
| `GPIO14` | 17 | `Net-(U1-GPIO14)` | Test point `G14` | Test point / spare I/O |
| `GPIO15` | 18 | `Net-(U1-GPIO15)` | Test point `G15` | Test point / spare I/O |
| `GPIO17` | 28 | `CS` | Display `J1` pin 8, breakout `J4` pin 5 | Display chip select |
| `GPIO18` | 29 | `SCK` | Display `J1` pin 9, breakout `J4` pin 6 | Display SPI clock |
| `GPIO19` | 30 | `MOSI` | Display `J1` pin 10, breakout `J4` pin 7 | Display SPI data |
| `GPIO20` | 31 | `DC` | Display `J1` pin 7, breakout `J4` pin 4 | Display data/command |
| `GPIO21` | 32 | `RST` | Display `J1` pin 11, breakout `J4` pin 8 | Display reset |
| `GPIO22` | 34 | `BL_PIN` | Backlight MOSFET gate through 100 Ohm | Backlight PWM/on-off |
| `RUN` | 26 | `RUN` | `RUN1` button, `J3` pin 6 | RP2040 reset/run |
| `SWCLK` | 24 | `SWCLK` | `J3` pin 5 | SWD clock |
| `SWDIO` | 25 | `SWDIO` | `J3` pin 4 | SWD data |

The RP2040 QSPI pins are connected to external flash `U2` and are not general-purpose firmware pins:

| RP2040 pin | Net | Flash pin |
|---|---|---|
| `QSPI_SCLK` | `/QSPI_SCLK` | `U2` pin 6 |
| `QSPI_SD0` | `/QSPI_SD0` | `U2` pin 5 |
| `QSPI_SD1` | `/QSPI_SD1` | `U2` pin 2 |
| `QSPI_SD2` | `/QSPI_SD2` | `U2` pin 3 |
| `QSPI_SD3` | `/QSPI_SD3` | `U2` pin 7 |
| `QSPI_SS` | `/QSPI_SS` | `U2` pin 1 |

### Eye Connectors

#### Brain I2C/Power Connector `J2`

| Pin | Net | Function |
|---:|---|---|
| 1 | `+5V` | 5 V input from brain |
| 2 | `SDA` | I2C SDA to RP2040 `GPIO4` |
| 3 | `SCL` | I2C SCL to RP2040 `GPIO5` |
| 4 | `GND` | Ground |

#### Debug Header `J3`

| Pin | Net | Function |
|---:|---|---|
| 1 | `+5V` | 5 V |
| 2 | `Net-(J3-Pin_2)` | Connected through `JP1`/`R7`; optional 3.3 V related node |
| 3 | `GND` | Ground |
| 4 | `SWDIO` | SWD data |
| 5 | `SWCLK` | SWD clock |
| 6 | `RUN` | RP2040 run/reset |
| 7 | `TX` | RP2040 UART TX (`GPIO0`) |
| 8 | `RX` | RP2040 UART RX (`GPIO1`) |

#### Display Connector `J1` (`LH128`)

| Pin | Net | Function |
|---:|---|---|
| 1 | `GND` | Ground |
| 2 | `BL` | Backlight supply/switched return path |
| 3 | `+3.3V` | Display 3.3 V |
| 4 | `+3.3V` | Display 3.3 V |
| 5 | `GND` | Ground |
| 6 | `GND` | Ground |
| 7 | `DC` | Display data/command from RP2040 `GPIO20` |
| 8 | `CS` | Display chip-select from RP2040 `GPIO17` |
| 9 | `SCK` | Display SPI clock from RP2040 `GPIO18` |
| 10 | `MOSI` | Display SPI MOSI from RP2040 `GPIO19` |
| 11 | `RST` | Display reset from RP2040 `GPIO21` |
| 12 | `GND` | Ground |

#### Display Breakout Header `J4`

`J4` exposes the same display interface in an 8-pin header:

| Pin | Net | Function |
|---:|---|---|
| 1 | `+3.3V` | 3.3 V |
| 2 | `GND` | Ground |
| 3 | `BL` | Backlight |
| 4 | `DC` | Display data/command |
| 5 | `CS` | Display chip select |
| 6 | `SCK` | Display SPI clock |
| 7 | `MOSI` | Display SPI data |
| 8 | `RST` | Display reset |

### Eye Firmware Notes

- The display is SPI write-only from the RP2040 schematic point of view: `CS`, `SCK`, `MOSI`, `DC`, `RST`, and `BL_PIN` are controlled by RP2040 firmware.
- Backlight is driven by `GPIO22` through `R1` into MOSFET `Q1`; use PWM if brightness control is desired.
- `D1` is a firmware-controllable status LED on `GPIO2`.
- `D2` and `D3` are power indicator LEDs on `+5V` and `+3.3V` rails.
- USB D+/D- pins on RP2040 are unconnected; programming/debug should use SWD/UART unless a bootloader is already present in flash.

## Mouth PCB

### Main ICs

| Ref | Part | Firmware relevance |
|---|---|---|
| `U1` | RP2040 | Mouth/LED matrix MCU |
| `U2` | W25Q32JVSS | External QSPI flash for RP2040 |
| `U3` | AP2112K-3.3 | 3.3 V regulator from 5 V input |
| `U4`, `U5` | 74AHCT244 | 3.3 V to 5 V level shifting/buffering for matrix outputs |
| `J5` | 2x8 connector | HUB75-style RGB matrix output |

### RP2040 Firmware Pin Map

| RP2040 GPIO/signal | Package pin | Net | Output after level shift | Matrix signal |
|---|---:|---|---|---|
| `GPIO0` | 2 | `TX` | n/a | UART TX/debug on `J3` pin 7 |
| `GPIO1` | 3 | `RX` | n/a | UART RX/debug on `J3` pin 8 |
| `GPIO2` | 4 | `Net-(D1-A)` | n/a | User/status LED |
| `GPIO4` | 6 | `SDA` | n/a | I2C SDA to brain on `J2` pin 2 |
| `GPIO5` | 7 | `SCL` | n/a | I2C SCL to brain on `J2` pin 3 |
| `GPIO6` | 8 | `PIN_R1` | `R1` | Upper red data |
| `GPIO7` | 9 | `PIN_G1` | `G1` | Upper green data |
| `GPIO8` | 11 | `PIN_B1` | `B1` | Upper blue data |
| `GPIO9` | 12 | `PIN_R2` | `R2` | Lower red data |
| `GPIO10` | 13 | `PIN_G2` | `G2` | Lower green data |
| `GPIO11` | 14 | `PIN_B2` | `B2` | Lower blue data |
| `GPIO12` | 15 | `PIN_E` | `E` | Row address E |
| `GPIO13` | 16 | `PIN_A` | `A` | Row address A |
| `GPIO14` | 17 | `PIN_B` | `B` | Row address B |
| `GPIO15` | 18 | `PIN_C` | `C` | Row address C |
| `GPIO16` | 27 | `PIN_D` | `D` | Row address D |
| `GPIO17` | 28 | `PIN_CLK` | `CLK` | Matrix pixel clock |
| `GPIO18` | 29 | `PIN_LAT` | `LAT` | Matrix latch/strobe |
| `GPIO19` | 30 | `PIN_OE` | `OE` | Matrix output enable |
| `RUN` | 26 | `RUN` | n/a | RP2040 reset/run on `J3` pin 6 |
| `SWCLK` | 24 | `SWCLK` | n/a | SWD clock on `J3` pin 5 |
| `SWDIO` | 25 | `SWDIO` | n/a | SWD data on `J3` pin 4 |

The RP2040 QSPI pins are connected to external flash `U2` and are not general-purpose firmware pins:

| RP2040 pin | Net | Flash pin |
|---|---|---|
| `QSPI_SCLK` | `/QSPI_SCLK` | `U2` pin 6 |
| `QSPI_SD0` | `/QSPI_SD0` | `U2` pin 5 |
| `QSPI_SD1` | `/QSPI_SD1` | `U2` pin 2 |
| `QSPI_SD2` | `/QSPI_SD2` | `U2` pin 3 |
| `QSPI_SD3` | `/QSPI_SD3` | `U2` pin 7 |
| `QSPI_SS` | `/QSPI_SS` | `U2` pin 1 |

### Mouth Connectors

#### External 5 V Power `J1`

| Pin | Net | Function |
|---:|---|---|
| 1 | `+5V` | 5 V input for board/matrix logic |
| 2 | `GND` | Ground |

#### Brain I2C/Power Connector `J2`

| Pin | Net | Function |
|---:|---|---|
| 1 | `+5V` | 5 V input from brain |
| 2 | `SDA` | I2C SDA to RP2040 `GPIO4` |
| 3 | `SCL` | I2C SCL to RP2040 `GPIO5` |
| 4 | `GND` | Ground |

#### Debug Header `J3`

| Pin | Net | Function |
|---:|---|---|
| 1 | `+5V` | 5 V |
| 2 | `Net-(J3-Pin_2)` | Connected through `JP1`/`R7`; optional 3.3 V related node |
| 3 | `GND` | Ground |
| 4 | `SWDIO` | SWD data |
| 5 | `SWCLK` | SWD clock |
| 6 | `RUN` | RP2040 run/reset |
| 7 | `TX` | RP2040 UART TX (`GPIO0`) |
| 8 | `RX` | RP2040 UART RX (`GPIO1`) |

#### HUB75-Style Matrix Connector `J5`

| `J5` pin | Net | Source |
|---:|---|---|
| 1 | `R1` | RP2040 `GPIO6` through `U4` + 22 Ohm series resistor |
| 2 | `G1` | RP2040 `GPIO7` through `U4` + 22 Ohm series resistor |
| 3 | `B1` | RP2040 `GPIO8` through `U4` + 22 Ohm series resistor |
| 4 | `GND` | Ground |
| 5 | `R2` | RP2040 `GPIO9` through `U4` + 22 Ohm series resistor |
| 6 | `G2` | RP2040 `GPIO10` through `U4` + 22 Ohm series resistor |
| 7 | `B2` | RP2040 `GPIO11` through `U4` + 22 Ohm series resistor |
| 8 | `E` | RP2040 `GPIO12` through `U5` + 22 Ohm series resistor |
| 9 | `A` | RP2040 `GPIO13` through `U4` + 22 Ohm series resistor |
| 10 | `B` | RP2040 `GPIO14` through `U4` + 22 Ohm series resistor |
| 11 | `C` | RP2040 `GPIO15` through `U5` + 22 Ohm series resistor |
| 12 | `D` | RP2040 `GPIO16` through `U5` + 22 Ohm series resistor |
| 13 | `CLK` | RP2040 `GPIO17` through `U5` + 22 Ohm series resistor |
| 14 | `LAT` | RP2040 `GPIO18` through `U5` + 22 Ohm series resistor |
| 15 | `OE` | RP2040 `GPIO19` through `U5` + 22 Ohm series resistor; also 10 kOhm pull-up to `+5V` |
| 16 | `GND` | Ground |

### Mouth Level Shifters

The mouth PCB uses two `74AHCT244` buffers powered from `+5V`. Their inputs are driven directly by RP2040 3.3 V GPIOs; AHCT inputs accept 3.3 V CMOS levels and output 5 V logic to the matrix connector.

| RP2040 net | Buffer input | Buffer output net | Connector net |
|---|---|---|---|
| `PIN_R1` | `U4` pin 2 | `U4` pin 18 | `R1` |
| `PIN_G1` | `U4` pin 4 | `U4` pin 16 | `G1` |
| `PIN_B1` | `U4` pin 6 | `U4` pin 14 | `B1` |
| `PIN_R2` | `U4` pin 8 | `U4` pin 12 | `R2` |
| `PIN_G2` | `U4` pin 17 | `U4` pin 3 | `G2` |
| `PIN_B2` | `U4` pin 15 | `U4` pin 5 | `B2` |
| `PIN_A` | `U4` pin 13 | `U4` pin 7 | `A` |
| `PIN_B` | `U4` pin 11 | `U4` pin 9 | `B` |
| `PIN_C` | `U5` pin 2 | `U5` pin 18 | `C` |
| `PIN_D` | `U5` pin 4 | `U5` pin 16 | `D` |
| `PIN_E` | `U5` pin 6 | `U5` pin 14 | `E` |
| `PIN_CLK` | `U5` pin 8 | `U5` pin 12 | `CLK` |
| `PIN_LAT` | `U5` pin 17 | `U5` pin 3 | `LAT` |
| `PIN_OE` | `U5` pin 15 | `U5` pin 5 | `OE` |

Both output-enable pins of `U4` are tied to `GND`, so all `U4` outputs are always enabled. `U5` output-enable pins are also tied to `GND`, so all used `U5` outputs are always enabled.

### Mouth Firmware Notes

- The matrix interface is HUB75-like: RGB data for two scan halves (`R1/G1/B1` and `R2/G2/B2`), row address lines `A/B/C/D/E`, pixel clock `CLK`, latch `LAT`, and output enable `OE`.
- `OE` has a 10 kOhm pull-up to `+5V` after the level shifter. Firmware should drive `PIN_OE` deliberately during initialization to avoid unwanted display output.
- All matrix outputs go through 22 Ohm series resistors after the level shifters.
- `D1` is a firmware-controllable status LED on `GPIO2`.
- `D2` and `D3` are power indicator LEDs on `+5V` and `+3.3V` rails.
- USB D+/D- pins on RP2040 are unconnected; programming/debug should use SWD/UART unless a bootloader is already present in flash.

## Suggested Firmware Interface Summary

### Brain ESP32-S3

| Interface | Signals | Pins |
|---|---|---|
| I2C bus | `SDA`, `SCL` | `IO8`, `IO9` |
| Ethernet SPI | `EthCS`, `MOSI`, `SCLK`, `MISO`, `INTn`, `RSTn` | `IO10`, `IO11`, `IO12`, `IO13`, `IO14`, `IO15` |
| Stepper | `STEP`, `DIR`, `TmcEN`, `UART`, `DIAG` | `IO16`, `IO17`, `IO18`, `IO21`, `IO38` |
| I2S speaker/mic | `BCLK`, `LRCLK`, `DIN`, `MicDATA` | `IO39`, `IO40`, `IO41`, `IO47` |
| Power control | `5V_EN`, `5VHP_EN`, `CE`, `BQINT`, `ALRT` | `IO1`, `IO2`, `IO6`, `IO7`, `IO42` |
| USB | `D-`, `D+` | native USB pins |
| Status LED | `D1` | `IO48` |

### Eye RP2040

| Interface | Signals | Pins |
|---|---|---|
| I2C to brain | `SDA`, `SCL` | `GPIO4`, `GPIO5` |
| Display SPI/control | `CS`, `SCK`, `MOSI`, `DC`, `RST`, `BL_PIN` | `GPIO17`, `GPIO18`, `GPIO19`, `GPIO20`, `GPIO21`, `GPIO22` |
| Debug UART | `TX`, `RX` | `GPIO0`, `GPIO1` |
| SWD | `SWCLK`, `SWDIO`, `RUN` | RP2040 SWD pins and `RUN` |
| Status LED | `D1` | `GPIO2` |

### Mouth RP2040

| Interface | Signals | Pins |
|---|---|---|
| I2C to brain | `SDA`, `SCL` | `GPIO4`, `GPIO5` |
| Matrix data | `R1`, `G1`, `B1`, `R2`, `G2`, `B2` | `GPIO6`, `GPIO7`, `GPIO8`, `GPIO9`, `GPIO10`, `GPIO11` |
| Matrix address | `A`, `B`, `C`, `D`, `E` | `GPIO13`, `GPIO14`, `GPIO15`, `GPIO16`, `GPIO12` |
| Matrix timing | `CLK`, `LAT`, `OE` | `GPIO17`, `GPIO18`, `GPIO19` |
| Debug UART | `TX`, `RX` | `GPIO0`, `GPIO1` |
| SWD | `SWCLK`, `SWDIO`, `RUN` | RP2040 SWD pins and `RUN` |
| Status LED | `D1` | `GPIO2` |

## Open Assumptions

- Brain connectors `J2`, `J4`, `J5`, and `J6` will be wired to the two eye displays and the mouth matrix in the final assembly. They are all electrically equivalent I2C/power ports and can be used interchangeably; the firmware distinguishes left eye, right eye, and mouth by I2C slave address, not by which brain connector is used.
- I2C addresses/protocols for the RP2040 coprocessors are a firmware design decision; the schematics only define the electrical bus.
- The eye display part is named `LH128` in the schematic. Its exact controller/protocol must be confirmed from the display module datasheet if initialization commands are not already known.

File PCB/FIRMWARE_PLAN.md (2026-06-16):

# SarcasmOS Firmware Plan

This document defines the planned firmware architecture for the SarcasmOS hardware. It complements `SCHEMATICS_FIRMWARE_INTERFACE.md`, which documents the electrical connections and pin mappings.

## Product Goal

SarcasmOS is a voice-assistant robot with three physical displays:

- Left eye display, using one `eye` PCB.
- Right eye display, using a second `eye` PCB.
- Mouth display, using one `mouth` PCB.

The `brain` PCB runs the main application on an ESP32-S3 using ESP-IDF. It handles voice-assistant processing, networking, web/API control, audio playback/capture, power/peripheral control, and animation coordination. The two eyes and the mouth are slave display controllers. The brain tells them what animation/state to play over I2C.

## Firmware Targets

| Target | MCU | Framework | Role |
|---|---|---|---|
| Brain | ESP32-S3-WROOM-1 | ESP-IDF | Main controller, networking, audio, I2C master, web/API, animation scheduler |
| Left eye | RP2040 | Pico SDK or compatible RP2040 stack | I2C slave, display renderer |
| Right eye | RP2040 | Pico SDK or compatible RP2040 stack | I2C slave, display renderer |
| Mouth | RP2040 | Pico SDK or compatible RP2040 stack | I2C slave, HUB75-style mouth renderer |

## High-Level Runtime Architecture

```text
User / network / web UI
        |
        v
ESP32-S3 brain firmware
  - Wi-Fi/Ethernet networking
  - Local web/API service
  - Voice assistant state machine
  - Audio playback and microphone capture
  - Animation scheduler
  - I2C master commands
        |
        +-- I2C --> Left eye RP2040  --> LH128 display
        +-- I2C --> Right eye RP2040 --> LH128 display
        +-- I2C --> Mouth RP2040     --> RGB matrix / mouth display
```

The existing web project at `Code/AI/Workflow/SarcasmOS-web/` is the behavioral reference for the embedded UI/API. Its current backend exposes chat/audio/status/history/command endpoints and the frontend has animation states like `speaking`, `thinking`, `thinking-audio`, and `thinking-long`. The ESP32 firmware should implement a smaller embedded equivalent appropriate for ESP-IDF resources.

## Brain Firmware Responsibilities

### Core Services

The ESP32-S3 brain firmware should provide these services:

| Service | Purpose | Hardware/interfaces |
|---|---|---|
| System init | Bring up clocks, NVS, event loop, logging, watchdogs | ESP-IDF core |
| Power control | Enable 5 V rails and monitor battery/charger | `5V_EN`, `5VHP_EN`, BQ25792, MAX17049 |
| I2C master | Control eyes, mouth, charger, fuel gauge | `SDA`=`IO8`, `SCL`=`IO9` |
| Display coordinator | Select animations and send commands to slaves | I2C display protocol |
| Audio output | Play TTS/assistant audio | MAX98357A over I2S |
| Audio input | Capture microphone audio | ICS-43434 over I2S |
| Networking | Serve API/UI and reach external AI services if used | Wi-Fi and/or W5500 Ethernet |
| Web/API | Embedded control/status interface | HTTP server |
| Assistant state machine | Coordinate listening/thinking/speaking/errors | Internal app logic |
| Diagnostics | Logs, status LED, health checks | UART0, LED, API |

### Brain ESP-IDF Modules

Recommended module boundaries:

| Module | Responsibilities |
|---|---|
| `app_main` | Boot sequence, task creation, dependency wiring |
| `board_pins` | Central pin definitions from schematic document |
| `power_manager` | Regulator enables, charger/fuel-gauge setup, battery state |
| `i2c_bus` | Shared I2C master driver, bus locking, scan, read/write helpers |
| `display_bus` | High-level I2C protocol for eyes and mouth |
| `animation_manager` | Current expression/animation state and transitions |
| `audio_out` | I2S speaker output through MAX98357A |
| `audio_in` | I2S microphone capture through ICS-43434 |
| `network_manager` | Wi-Fi and/or W5500 Ethernet bring-up and reconnection |
| `web_server` | HTTP API and static UI serving |
| `assistant_core` | Voice assistant state machine and backend/cloud integration |
| `storage` | NVS config: Wi-Fi credentials, I2C addresses, preferences |
| `diagnostics` | Health/status endpoints, logging helpers, reset reasons |

## I2C Device Model

### Bus Participants

All runtime display commands use the brain I2C bus.

| Device | Role | Address plan |
|---|---|---|
| Left eye RP2040 | I2C slave display controller | Unique fixed/configured address |
| Right eye RP2040 | I2C slave display controller | Unique fixed/configured address |
| Mouth RP2040 | I2C slave display controller | Unique fixed/configured address |
| BQ25792 | Charger IC | Datasheet-defined address |
| MAX17049 | Fuel gauge IC | Datasheet-defined address |

Suggested display slave defaults, unless they conflict with the power-management ICs or existing firmware:

| Device | Suggested address |
|---|---:|
| Left eye | `0x30` |
| Right eye | `0x31` |
| Mouth | `0x32` |

These are firmware choices. The schematic has no hardware address-selection pins for the eye boards, so each eye must be provisioned with its own role/address in firmware or persistent configuration.

### Address Provisioning Options

Choose one provisioning method before writing production firmware:

| Option | How it works | Pros | Cons |
|---|---|---|---|
| Separate firmware builds | Flash left-eye and right-eye binaries with different compile-time addresses | Simple and reliable | Must track which binary is flashed to which board |
| NVM role config | Same binary, role stored in RP2040 flash/config sector | One firmware image | Needs provisioning tool or command path |
| I2C claim command | Brain assigns role during setup and slave stores it | Flexible | Needs temporary unique identity or one-at-a-time provisioning |

Recommended first implementation: separate firmware builds or a build-time `DEVICE_ROLE` setting for `left_eye`, `right_eye`, and `mouth`.

## Display I2C Protocol

The display boards should expose a simple register/command protocol. Keep commands small and let each RP2040 render animations locally. The brain should send animation intent, not full framebuffers, except for debug/testing.

### Common Packet Format

Use a compact binary command frame:

| Byte(s) | Field | Description |
|---:|---|---|
| 0 | `version` | Protocol version, start at `0x01` |
| 1 | `command` | Command ID |
| 2 | `sequence` | Incrementing command sequence number |
| 3 | `length` | Payload length in bytes |
| 4..N | `payload` | Command-specific payload |
| N+1 | `crc8` | Optional CRC-8 over prior bytes |

For early bring-up, CRC can be omitted if ESP-IDF/Pico I2C reliability is sufficient at the chosen bus speed. For production, include it to detect malformed animation commands.

### Common Commands

| Command | ID | Payload | Applies to | Purpose |
|---|---:|---|---|---|
| `PING` | `0x01` | none | all | Check device presence |
| `GET_INFO` | `0x02` | none | all | Read role, firmware version, display type |
| `SET_BRIGHTNESS` | `0x10` | `uint8 brightness` | all | Set display/backlight brightness, 0-255 |
| `SET_ANIMATION` | `0x20` | `animation_id`, options | all | Start named animation |
| `SET_EXPRESSION` | `0x21` | `expression_id`, options | all | Set static facial expression |
| `SYNC` | `0x22` | `timestamp_ms` or phase | all | Synchronize animations across displays |
| `STOP` | `0x23` | none | all | Stop current animation / blank display |
| `SET_PARAM` | `0x30` | key/value | all | Adjust animation speed, intensity, etc. |
| `DEBUG_FRAME` | `0x7E` | small display-specific frame data | debug only | Test rendering path |
| `RESET` | `0x7F` | magic value | all | Soft-reset display firmware |

### Suggested Animation IDs

| Animation | ID | Eye behavior | Mouth behavior |
|---|---:|---|---|
| `idle` | `0x00` | Neutral eyes, occasional blink | Neutral mouth/off or idle line |
| `listening` | `0x01` | Focused/awake eyes | Subtle listening indicator |
| `thinking` | `0x02` | Looking around, squint/pulse | Thinking animation |
| `thinking_audio` | `0x03` | Stronger animated attention | Audio processing indicator |
| `thinking_long` | `0x04` | Impatient/hard squint | Long wait animation |
| `speaking` | `0x05` | Blink/expressive speaking state | Mouth viseme/amplitude animation |
| `happy` | `0x06` | Happy eyes | Smile/mouth expression |
| `angry` | `0x07` | Angry/squint eyes | Angry mouth |
| `error` | `0x08` | Error/glitch eyes | Error/glitch mouth |
| `sleep` | `0x09` | Closed/off eyes | Blank/off mouth |

These names intentionally mirror the web prototype animation states where possible.

### Readback Registers

Each slave should support readback after command writes:

| Register/response | Fields |
|---|---|
| Device info | role, firmware version, protocol version, capabilities |
| Status | current animation, busy flag, error code, uptime |
| Last command result | last sequence, ACK/NACK, error code |
| Metrics | dropped commands, render FPS, I2C error count |

## Brain Display Control Flow

The brain should never need to manually render eye or mouth pixels for normal operation. It should run an animation scheduler:

1. Detect high-level assistant state: idle, listening, thinking, speaking, error.
2. Convert state to desired animation per display.
3. Send `SET_ANIMATION` to left eye, right eye, and mouth.
4. Send `SYNC` so all displays align timing.
5. During speaking, send amplitude/viseme parameters to the mouth periodically.
6. On state changes, send new animations only when necessary to avoid I2C spam.

### Speaking Animation

For speech, the brain can coordinate mouth movement in two stages:

| Stage | Behavior |
|---|---|
| Bring-up | Mouth board plays autonomous `speaking` animation at fixed intensity |
| Improved | Brain extracts audio amplitude envelope and sends periodic intensity values |
| Advanced | Brain or TTS pipeline sends viseme/phoneme timing to mouth board |

Recommended first implementation: send `SET_ANIMATION(speaking)` when audio starts and `SET_ANIMATION(idle)` when audio ends. Add amplitude later.

## Eye Firmware Plan

Each eye RP2040 firmware should be identical except for role/address configuration.

### Eye Firmware Responsibilities

| Area | Requirement |
|---|---|
| I2C slave | Listen on configured left/right address and parse display protocol |
| Display driver | Initialize and draw to the `LH128` display over SPI-like pins |
| Animation engine | Render local eye animations from command IDs |
| Backlight | Control `BL_PIN` on `GPIO22`, including brightness/PWM if supported |
| Status LED | Use `GPIO2` for heartbeat/error/debug |
| Watchdog | Recover if animation loop or I2C handling stalls |
| Debug | UART and SWD support through `J3` |

### Eye Pin Use

| Function | RP2040 pin |
|---|---|
| I2C SDA | `GPIO4` |
| I2C SCL | `GPIO5` |
| Display CS | `GPIO17` |
| Display SCK | `GPIO18` |
| Display MOSI | `GPIO19` |
| Display DC | `GPIO20` |
| Display RST | `GPIO21` |
| Backlight | `GPIO22` |
| Status LED | `GPIO2` |
| Debug UART TX/RX | `GPIO0` / `GPIO1` |

### Eye Open Items

- Confirm the exact `LH128` display controller and initialization sequence.
- Decide whether left/right orientation is handled by firmware transform, display mounting, or separate configuration.
- Decide exact I2C addresses for left and right eye.

## Mouth Firmware Plan

The mouth RP2040 firmware renders animations on the HUB75-style matrix connector through 74AHCT244 level shifters.

### Mouth Firmware Responsibilities

| Area | Requirement |
|---|---|
| I2C slave | Listen on configured mouth address and parse display protocol |
| Matrix driver | Generate RGB data, row addressing, `CLK`, `LAT`, and `OE` timing |
| Animation engine | Render mouth expressions and speaking motion locally |
| Brightness | Use PWM/bitplane timing and `OE` to control brightness |
| Status LED | Use `GPIO2` for heartbeat/error/debug |
| Watchdog | Recover if matrix scan or I2C handling stalls |
| Debug | UART and SWD support through `J3` |

### Mouth Pin Use

| Matrix signal | RP2040 GPIO | Notes |
|---|---|---|
| `R1` | `GPIO6` | Upper red data |
| `G1` | `GPIO7` | Upper green data |
| `B1` | `GPIO8` | Upper blue data |
| `R2` | `GPIO9` | Lower red data |
| `G2` | `GPIO10` | Lower green data |
| `B2` | `GPIO11` | Lower blue data |
| `E` | `GPIO12` | Row address E |
| `A` | `GPIO13` | Row address A |
| `B` | `GPIO14` | Row address B |
| `C` | `GPIO15` | Row address C |
| `D` | `GPIO16` | Row address D |
| `CLK` | `GPIO17` | Pixel clock |
| `LAT` | `GPIO18` | Latch/strobe |
| `OE` | `GPIO19` | Output enable/brightness |

### Mouth Open Items

- Confirm matrix resolution, scan ratio, color depth, and row-address use of `E`.
- Decide the first set of mouth expression assets.
- Decide whether speaking motion is amplitude-only or viseme-based.

## Brain Audio Plan

### Output

The brain drives `U4` MAX98357A over I2S:

| Signal | ESP32 pin |
|---|---|
| `BCLK` | `IO39` |
| `LRCLK` | `IO40` |
| `DIN` | `IO41` |

ESP-IDF should use the I2S standard TX driver. 

### Input

The brain reads `MK1` ICS-43434 digital microphone over I2S:

| Signal | ESP32 pin |
|---|---|
| `BCLK` | `IO39` |
| `LRCLK` | `IO40` |
| `MicDATA` | `IO47` |

Because the speaker amp and microphone share `BCLK`/`LRCLK`, firmware should configure I2S carefully. If simultaneous full-duplex operation is needed, validate ESP-IDF I2S channel support and timing with this shared-clock topology.

## Brain Networking and Web Plan

### Networking

The brain should support at least one network path:

| Interface | Hardware | Firmware role |
|---|---|---|
| Wi-Fi | ESP32-S3 radio | Primary embedded web/API and internet access |
| Ethernet | W5500 over SPI | Wired network option |

W5500 pins:

| Signal | ESP32 pin |
|---|---|
| `EthCS` | `IO10` |
| `MOSI` | `IO11` |
| `SCLK` | `IO12` |
| `MISO` | `IO13` |
| `INTn` | `IO14` |
| `RSTn` | `IO15` |

### Embedded Web/API

The ESP32 should expose a compact web/API surface inspired by `SarcasmOS-web`:

| Endpoint | Method | Purpose |
|---|---|---|
| `/api/status` | `GET` | Return brain status, battery, network, display slave status |
| `/api/command` | `POST` | Trigger animation/expression/test commands |
| `/api/chat/text` | `POST` | Send text to assistant pipeline if implemented on-device/proxy |
| `/api/chat/audio` | `POST` | Upload/capture audio for assistant pipeline if supported |
| `/api/audio/{id}` | `GET` | Serve generated/cached audio if stored locally |
| `/api/config` | `GET/POST` | Read/update Wi-Fi, device addresses, preferences |

For the first embedded milestone, implement `/api/status` and `/api/command` only. The full AI pipeline can remain external until storage, RAM, and network behavior are validated on the ESP32-S3.

## Assistant State Machine

The firmware should centralize assistant behavior as explicit states:

| State | Entry action | Display command | Exit condition |
|---|---|---|---|
| `booting` | Initialize hardware | `thinking` or boot animation | Init complete |
| `idle` | Wait for input | `idle` | Button/API/wake/audio event |
| `listening` | Capture microphone/audio | `listening` | Speech end or timeout |
| `thinking` | Process STT/LLM/TTS or wait for backend | `thinking` | Response ready or timeout |
| `speaking` | Play audio | `speaking` | Audio playback complete |
| `error` | Log/report failure | `error` | Recovery timer/API reset |
| `sleep` | Dim displays | `sleep` | Wake event |

The state machine is the owner of display animation intent. Individual modules should request state transitions instead of directly commanding displays.

## Bring-Up Milestones

### Milestone 1: Electrical/Board Bring-Up

| Task | Success criteria |
|---|---|
| Brain boots ESP-IDF | Serial logs over UART0/USB |
| Enable 5 V rails | `+5V` and `5VHP` switch as expected |
| I2C scan | Charger, fuel gauge, eyes, and mouth detected |
| RP2040 slaves boot | Status LED heartbeat on each display board |
| Debug access | SWD/UART works on eye and mouth |

### Milestone 2: Display Slave Firmware

| Task | Success criteria |
|---|---|
| Eye display init | Each eye shows test pattern |
| Mouth matrix init | Mouth shows test pattern |
| I2C command parser | `PING`, `GET_INFO`, `SET_BRIGHTNESS` work |
| Animation command | `SET_ANIMATION(idle/thinking/speaking)` works |
| Unique addresses | Left eye, right eye, and mouth respond independently |

### Milestone 3: Brain Peripheral Firmware

| Task | Success criteria |
|---|---|
| W5500 or Wi-Fi networking | Brain reachable over network |
| HTTP API | `/api/status` and `/api/command` work |
| Audio out | Test sound plays through MAX98357A/speaker |
| Microphone input | Captured PCM shows valid signal |
| Power telemetry | Charger/fuel gauge status visible in API |

### Milestone 4: Integrated Assistant Behavior

| Task | Success criteria |
|---|---|
| State machine | Idle/listening/thinking/speaking transitions are stable |
| Display coordination | Three displays change animations together |
| Audio/display sync | Mouth speaking animation starts/stops with audio |
| Web command control | Web/API can trigger expressions and test animations |
| Failure handling | Missing slave/network/audio errors are reported cleanly |

## Configuration Data

Store these settings in brain NVS:

| Key | Purpose |
|---|---|
| `wifi.ssid`, `wifi.password` | Wi-Fi station configuration |
| `net.mode` | Wi-Fi, Ethernet, or both |
| `i2c.left_eye_addr` | Left eye I2C address |
| `i2c.right_eye_addr` | Right eye I2C address |
| `i2c.mouth_addr` | Mouth I2C address |
| `display.brightness` | Global brightness |
| `audio.volume` | Speaker volume/scaling |
| `assistant.backend_url` | Optional external AI/backend URL |

Store these settings in each RP2040 display board flash/config:

| Key | Applies to | Purpose |
|---|---|---|
| `device.role` | eyes/mouth | `left_eye`, `right_eye`, or `mouth` |
| `i2c.address` | eyes/mouth | Slave address |
| `display.orientation` | eyes | Left/right orientation/mirroring |
| `display.brightness_limit` | eyes/mouth | Maximum safe brightness |

## Open Decisions

These must be decided before final firmware implementation:

- Exact I2C addresses for left eye, right eye, and mouth. - up to firmware development decision, not important 
- How RP2040 board identity is provisioned. - different I2C addresses in firmware config
- Exact `LH128` display controller and initialization sequence. (
        Use SPI at 24–62.5 MHz depending on wiring quality.
Full framebuffer at RGB565 is:
240 × 240 × 2 = 115,200 bytes, which fits easily in RP2040 RAM.
The display is round, but the controller still uses a 240×240 square address space. You must clip/mask corners in software if needed.
Color format is normally RGB565.
)

- Mouth matrix resolution, scan rate, and color depth. -  (
Mouth display:
- Resolution: 128 × 64 RGB pixels
- Interface: HUB75/HUB75E
- Scan rate: 1/32 scan
- Address lines: A, B, C, D, E
- Pixel format: RGB
- Recommended framebuffer: RGB565
- Recommended output/PWM depth: 4 bits per color channel minimum
- Panel power: 5 V, up to 4 A per module)

- Whether the AI pipeline runs on the ESP32, proxies to a local server, or calls cloud APIs directly.
- Whether Wi-Fi, W5500 Ethernet, or both are required for the first release. wifi, is mandatory, ethernet able to be used, but disabled by default
- Whether speech-mouth sync is amplitude-based or viseme/phoneme-based. - whatever is easier to implement

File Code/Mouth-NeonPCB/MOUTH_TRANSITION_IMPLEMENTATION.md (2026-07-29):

# Mouth-NeonPCB animation transition implementation

## Scope

This document was the implementation plan for `Code/Mouth-NeonPCB`. The
mouth-side work is now implemented:

- the firmware captures the currently visible RGB565 image and performs an
  interruptible 200 ms blend;
- destination animation timing restarts at frame zero;
- ESP-NOW animation commands accept a transition token and duration;
- status protocol version 3 reports token, active state, and progress;
- the local tester and desktop emulator use the same transition behavior;
- `X` or `--no-transitions` disables emulator blending for sprite editing.

The Eye completion reporting and Brain synchronization barrier remain separate
codebase changes described by the linked documents. No firmware was uploaded
as part of the mouth implementation.

The mouth must not decide when the eyes have finished their outgoing
animation. The Brain owns that synchronization barrier. The mouth receives its
new animation only after the Brain has confirmed that both eyes activated the
same target state. When that command arrives, the mouth blends from its
currently displayed image into the first frame of the requested animation
instead of switching instantly.

See also:

- [`EYE_TRANSITION_IMPLEMENTATION.md`](EYE_TRANSITION_IMPLEMENTATION.md)
- [`BRAIN_TRANSITION_IMPLEMENTATION.md`](BRAIN_TRANSITION_IMPLEMENTATION.md)

## Required visible behavior

1. Keep rendering the current mouth animation while the Brain waits for both
   eyes.
2. On a new `SET_ANIMATION`, capture the exact currently visible mouth image.
3. Start the destination animation at frame zero.
4. Blend from the captured image to the live destination image over 200 ms.
5. Continue advancing the destination animation during the blend.
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

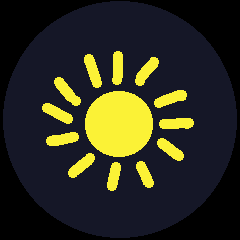
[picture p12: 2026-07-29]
Code/Eye/png animations/source/sunny/sunny1.png

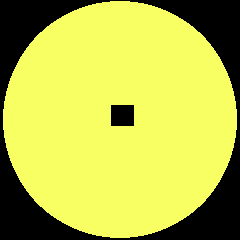
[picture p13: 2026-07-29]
Code/Eye/png animations/source/idle/idle5.png

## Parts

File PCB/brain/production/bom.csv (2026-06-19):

Designator | Footprint | Quantity | Value | LCSC Part #
BOOT1, EN1 | SW_SPST_TS-1088-xR025 | 2 | SW_Push | C720477
BT1, BT2 | PinHeader_1x02_P2.54mm_Vertical | 2 | Battery_Cell
C1, C15, C2, C29, C47, C51, C56, C92 | 0603 | 8 | 0.1uF | C696916
C10, C11, C12, C13, C4, C60, C61, C63, C7, C81, C84, C88, C89, C93, C95 | 0603 | 15 | 10uF | C194427
C14, C16, C90 | 0603 | 3 | 1uF | C106858
C17, C18, C19, C20, C21, C22, C23, C26, C27, C33, C34, C35, C37, C38, C39, C41, C52, C53, C54, C55 | 0603 | 20 | 10uF | C194427
C24 | 0603 | 1 | 1nF | C1588
C25, C28, C36, C40, C59, C62, C64, C65, C66, C67, C68, C69, C8, C96 | 0402 | 14 | 0.1uF | C77020
C3, C44, C75, C76 | 0603 | 4 | 10nF | C309036
C30, C31 | 0603 | 2 | 47nF | C1622
C32, C77 | 0603 | 2 | 4.7uF | C19666
C42, C94 | 0805 | 2 | 22uF | C162295
C43, C48, C49, C50, C57, C58 | 0805 | 6 | 22uF | C162295
C45 | 0603 | 1 | 2.7nF | C1609
C46 | 0603 | 1 | 33pF | C1663
C5, C6 | 0603 | 2 | 220pF | C388907
C70, C71 | 0603 | 2 | 15pF | C1644
C72, C79 | 0603 | 2 | 22nF | C21122
C73, C74 | 0603 | 2 | 6.8nF | C107097
C78 | 1206 | 1 | 1nF/2kV | C23631
C80, C83, C85, C87 | 0603 | 4 | 0.22uF | C97857
C82, C9 | 0402 | 2 | 0.1uF | C77020
C86, C91 | CAP-SMD_BD6.3-L6.6-W6.6-FD | 2 | 22uF | C72505
D1, D10, D11, D2, D3, D4, D6, D7, D8, D9 | 0603 | 10 | RED_LED | C19171390
D5 | SMB_L4.6-W3.6-LS5.3-RD | 1 | SMBJ15A | C83846
F1 | 1812 | 1 | 16V 2.6A | C438899
FB1, FB2 | 0603 | 2 | FerriteBead | C88989
FB3 | 0603 | 1 | CBW160808U601T | C139183
J1 | TerminalBlock_Phoenix_PT-1,5-2-5.0-H_1x02_P5.00mm_Horizontal | 1 | Screw_Terminal_01x02 | C474881
J10 | PinHeader_2x06_P2.54mm_Vertical | 1 | Conn_01x12
J11, J2, J4, J5, J6 | JST_XH_B4B-XH-A_1x04_P2.50mm_Vertical | 5 | Conn_01x04 | C144395
J12 | JST_XH_B3B-XH-A_1x03_P2.50mm_Vertical | 1 | BAT | C144394
J13 | JST_XH_B5B-XH-A_1x05_P2.50mm_Vertical | 1 | Conn_01x05 | C157991
J14 | PinSocket_1x02_P2.54mm_Vertical | 1 | Conn_01x02
J3 | RJ45_Hanrun_HR911105A_Horizontal | 1 | RJ45_Hanrun_HR911105A_Horizontal | C12074
J7, J8 | PinSocket_1x06_P2.54mm_Vertical | 2 | Conn_01x06
J9 | CONN-TH_4P-P2.54_MX128-2.54-GN01-04P-CU-Y-A | 1 | Motor | C5188444
L1 | IND-SMD_L7.1-W6.5-P5.60 | 1 | 1.0 uH | C87572
L2 | IND-SMD_L11.5-W10.0_SMMS1040 | 1 | 3.3uH | C149592
L3, L4 | IND-SMD_L5.0-W5.0 | 2 | 4.7uH | C354606
LS1 | JST_XH_B2B-XH-AM_1x02_P2.50mm_Vertical | 1 | Speaker | C158012
MK1 | InvenSense_ICS-43434-6_3.5x2.65mm | 1 | ICS-43434 | C5656610
Q1, Q2 | VSON-8_3.3x3.3mm_P0.65mm_NexFET | 2 | CSD17577Q3A | C201632
R1, R30, R39 | 0603 | 3 | 1M | C163869
R10, R11, R40, R41, R6, R7, R8, R9 | 0603 | 8 | 1k | C112433
R12, R13 | 0603 | 2 | 4.7k | C2904521
R14, R15 | 0603 | 2 | 330R | C859100
R16 | 0603 | 1 | 100R | C5123610
R17 | 0603 | 1 | 6.04k | C25977
R18, R23, R25, R28, R29, R4, R52, R53, R54, R55, R56, R57 | 0603 | 12 | 10k | C2930027
R19 | 0603 | 1 | 30.9k | C2930090
R2, R3 | 0603 | 2 | 5.11k | C23067
R20 | 0603 | 1 | 68.1k | C861521
R21 | 0603 | 1 | 30.31k
R22 | 0603 | 1 | 5.24k
R24 | 0603 | 1 | 2.2k | C7336403
R26 | 0603 | 1 | 15.8k | C54973935
R27 | 0603 | 1 | 52.3k | C23198
R31, R32, R34, R35 | 0603 | 4 | 49.9R | C23185
R33 | 0603 | 1 | 10R | C5123582
R36, R37 | 0603 | 2 | 300R | C114617
R38 | 0603 | 1 | 12.4k | C2482548
R42, R43 | 0603 | 2 | 6.8k | C103776
R44, R45 | 1206 | 2 | 0.05R | C46961736
R46, R47, R48, R49, R50 | 0603 | 5 | 20k | C4333405
R5 | 0603 | 1 | 47k | C2907042
R51 | 0603 | 1 | 33k | C881242
R58, R59 | 0603 | 2 | 100k | C2906980
R60, R61 | 0402 | 2 | 22R | C2929994
RV1 | RES-ADJ-SMD_3P-L3.8-W3.7_VGF39NCHXT | 1 | 10k | C22461454
TH1 | PinHeader_1x02_P2.54mm_Vertical | 1 | 10k
TP1, TP2, TP3, TP4, TP5, TP6, TP7 | TestPoint_Pad_D1.5mm | 7 | TestPoint
U1 | ESP32-S3-WROOM-1U | 1 | ESP32-S3-WROOM-1 | C2913199
U10 | WSON-8_L2.0-W2.0-P0.50-BL-EP0.9 | 1 | MAX17049G+T10 | C18185545
U11 | SOIC-8-1EP_3.9x4.9mm_P1.27mm_EP2.29x3mm_ThermalVias | 1 | AP64501SP-13 | C2071517
U12 | TSOT-23-6 | 1 | AP63205WU | C2071056
U14 | TSOT-23-6 | 1 | AP63203WU | C780769
U2 | VQFN-28-1EP_5x5mm_P0.5mm_EP3.7x3.7mm_ThermalVias | 1 | TMC2209-LA | C2150710
U3 | LQFP-48_7x7mm_P0.5mm | 1 | W5500 | C32843
U4 | TQFN-16-1EP_3x3mm_P0.5mm_EP1.23x1.23mm | 1 | MAX98357A | C910544
U5 | SOT-323_SC-70 | 1 | TPD2E2U06DCK | C1855726
U7 | SOT-23-6_L2.9-W1.6-P0.95-LS2.8-BL | 1 | R5460N214AF-TR-FE | C259719
U8 | SOT-23-6 | 1 | CH221K | C5125736
U9 | Texas_RQM0029A_VQFN-29_4x4mm_P0.4mm | 1 | BQ25792 | C2862876
USB1 | USB-C-SMD_TYPE-C-6PIN-2MD-073 | 1 | TYPE-C 16PIN 2MD(073) | C2765186
Y1 | Crystal_SMD_3225-4Pin_3.2x2.5mm | 1 | 25MHz | C13740

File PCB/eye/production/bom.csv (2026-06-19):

Designator | Footprint | Quantity | Value | LCSC Part #
BOOT1, RUN1 | SW_SPST_TS-1088-xR025 | 2 | SW_Push | C720477
C1, C10, C11, C12, C13, C14, C15, C8, C9 | 0603 | 9 | 0.1uF | C696916
C16, C17, C18 | 0603 | 3 | 1uF | C106858
C2, C3 | 0603 | 2 | 33pF | C1663
C4, C5, C6, C7 | 0805 | 4 | 10uF | C5448891
D1, D2, D3 | 0603 | 3 | RED_LED | C19171390
J1 | LH128R | 1 | LH128
J2 | JST_XH_B4B-XH-A_1x04_P2.50mm_Vertical | 1 | Conn_01x04 | C144395
J3 | PinHeader_2x04_P2.54mm_Vertical | 1 | Conn_01x08 | C5383105
J4 | PinHeader_2x04_P2.54mm_Vertical | 1 | Conn_01x08 | C5383105
Q1 | SOT-23 | 1 | AO3400A | C20917
R1, R7 | 0603 | 2 | 100R | C5123610
R10, R11, R3, R8, R9 | 0603 | 5 | 1k | C112433
R2, R4 | 0603 | 2 | 10k | C2930027
R5 | 0603 | 1 | 100k | C2906980
R6 | 0603 | 1 | 22R | C103434
U1 | QFN-56-1EP_7x7mm_P0.4mm_EP3.2x3.2mm | 1 | RP2040 | C2040
U2 | SOIC-8_5.3x5.3mm_P1.27mm | 1 | W25Q128JVSIQ | C97521
U3 | SOT-23-5 | 1 | AP2112K-3.3 | C51118
Y1 | Crystal_SMD_3225-4Pin_3.2x2.5mm | 1 | 12MHz | C9002

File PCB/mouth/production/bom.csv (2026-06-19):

Designator | Footprint | Quantity | Value | LCSC Part #
BOOT1, RUN1 | SW_SPST_TS-1088-xR025 | 2 | SW_Push | C720477
C1, C10, C11, C12, C13, C14, C15, C19, C20, C8, C9 | 0603 | 11 | 0.1uF | C696916
C16, C17, C18, C21 | 0603 | 4 | 1uF | C106858
C2, C3 | 0603 | 2 | 33pF | C1663
C22, C4, C5, C6, C7 | 0805 | 5 | 10uF | C5448891
D1, D2, D3 | 0603 | 3 | RED_LED | C19171390
J1 | TerminalBlock_Phoenix_PT-1,5-2-5.0-H_1x02_P5.00mm_Horizontal | 1 | Screw_Terminal_01x02 | C474881
J2 | JST_XH_B4B-XH-A_1x04_P2.50mm_Vertical | 1 | Conn_01x04 | C144395
J3 | PinHeader_2x04_P2.54mm_Vertical | 1 | Conn_01x08 | C5383105
J5 | PinSocket_2x08_P2.54mm_Vertical | 1 | Conn_02x08_Odd_Even | C30734
R10, R11, R3, R8, R9 | 0603 | 5 | 1k | C112433
R13, R14, R15, R16, R17, R18, R19, R20, R21, R22, R23, R24, R25, R26 | 0603 | 14 | 22R | C103434
R2, R4, R5 | 0603 | 3 | 10k | C2930027
R7 | 0603 | 1 | 100R | C5123610
U1 | QFN-56-1EP_7x7mm_P0.4mm_EP3.2x3.2mm | 1 | RP2040 | C2040
U2 | SOIC-8_5.3x5.3mm_P1.27mm | 1 | W25Q128JVSIQ | C97521
U3 | SOT-23-5 | 1 | AP2112K-3.3 | C51118
U4, U5 | SSOP-20_4.4x6.5mm_P0.65mm | 2 | 74AHCT244 | C2868870
U6 | CONN-TH_P5.00_KF301-5.0-2P | 1 | KF301-5.0-2P | C474881
Y1 | Crystal_SMD_3225-4Pin_3.2x2.5mm | 1 | 12MHz | C9002

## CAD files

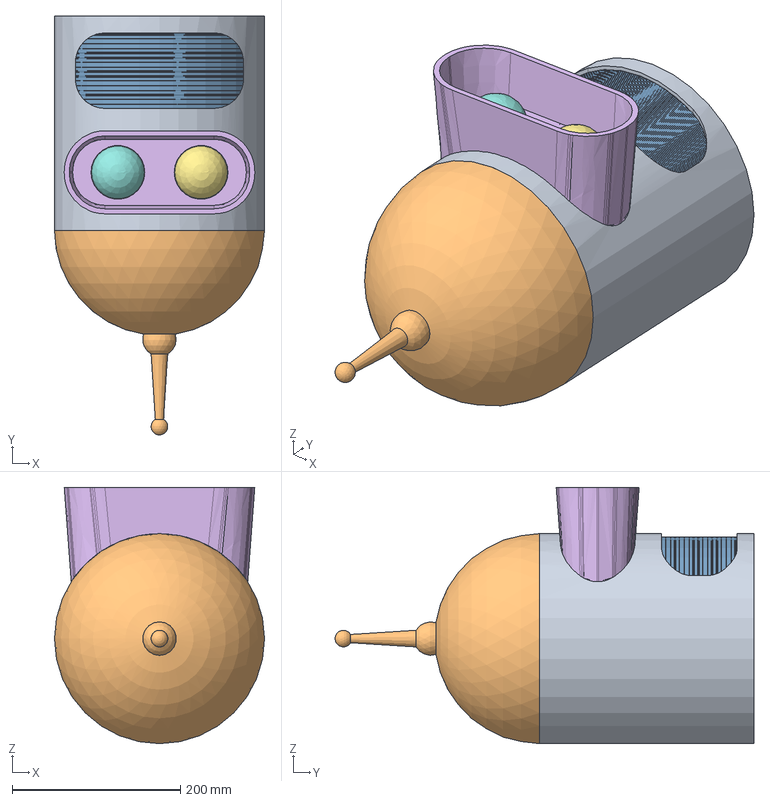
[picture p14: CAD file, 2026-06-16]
CAD/newSarcasmos.FCStd
250.0 x 498.5 x 305.0 mm
R_0603_1608Metric182
PinHeader_2x04_P254mm_Vertical002
C_0805_2012Metric034
C_0603_1608Metric200
SW_SPST_TS-1088-xR037
R_0603_1608Metric184
R_0603_1608Metric186
C_0603_1608Metric202
R_0603_1608Metric188
R_0603_1608Metric190
R_0603_1608Metric192
Crystal_SMD_3225-4Pin_3.2x2.5mm006
C_0603_1608Metric204
QFN-56-1EP_7x7mm_P0.4mm_EP3.2x3.2mm002
R_0603_1608Metric194
C_0603_1608Metric206
JST_B4B_XH_A007
C_0603_1608Metric208
R_0603_1608Metric196
SOIC-8_5.3x5.3mm_P1.27mm002
R_0603_1608Metric198
C_0603_1608Metric210
R_0603_1608Metric200
R_0603_1608Metric202
C_0805_2012Metric036
R_0603_1608Metric204
SOT-23-005
C_0603_1608Metric212
LED_0603_1608Metric032
R_0603_1608Metric206
C_0603_1608Metric214
LED_0603_1608Metric034
C_0603_1608Metric216
R_0603_1608Metric208
R_0603_1608Metric210
C_0603_1608Metric218
SSOP-20_4.4x6.5mm_P0.65mm
LED_0603_1608Metric036
R_0603_1608Metric212
R_0603_1608Metric214
TerminalBlock_Phoenix_PT-1,5-2-5.0-H_1x02_P5.00mm_Horizontal
C_0805_2012Metric038
R_0603_1608Metric216
C_0603_1608Metric220
R_0603_1608Metric218
C_0603_1608Metric222
C_0603_1608Metric224
SW_SPST_TS-1088-xR039
R_0603_1608Metric220
SSOP-20_4.4x6.5mm_P0.65mm002
R_0603_1608Metric222
R_0603_1608Metric224
R_0603_1608Metric226
C_0805_2012Metric040
C_0603_1608Metric226
C_0805_2012Metric042
C_0603_1608Metric228
C_0603_1608Metric230
C_0603_1608Metric232
PinSocket_2x08_P2.54mm_Vertical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

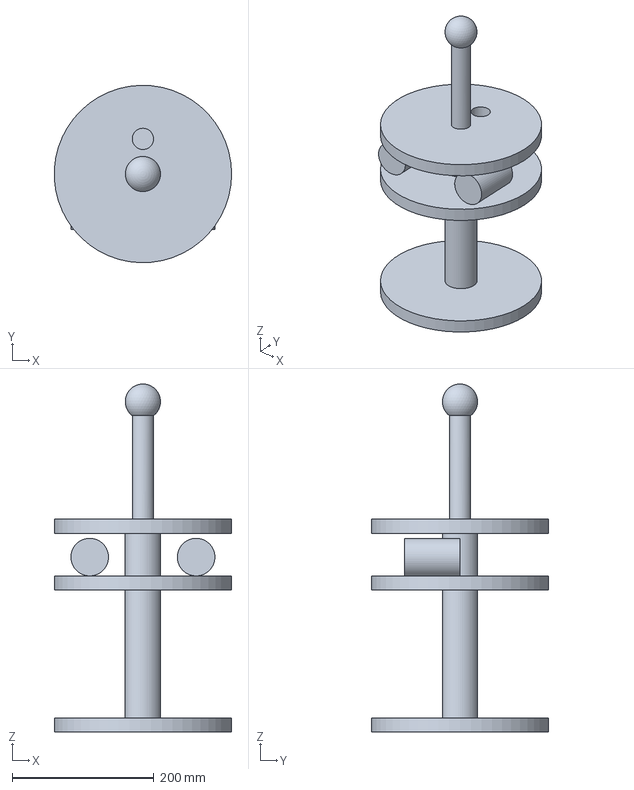
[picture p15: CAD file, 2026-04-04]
CAD/interior SarcasmOS.FCStd
249.8 x 249.9 x 490.5 mm

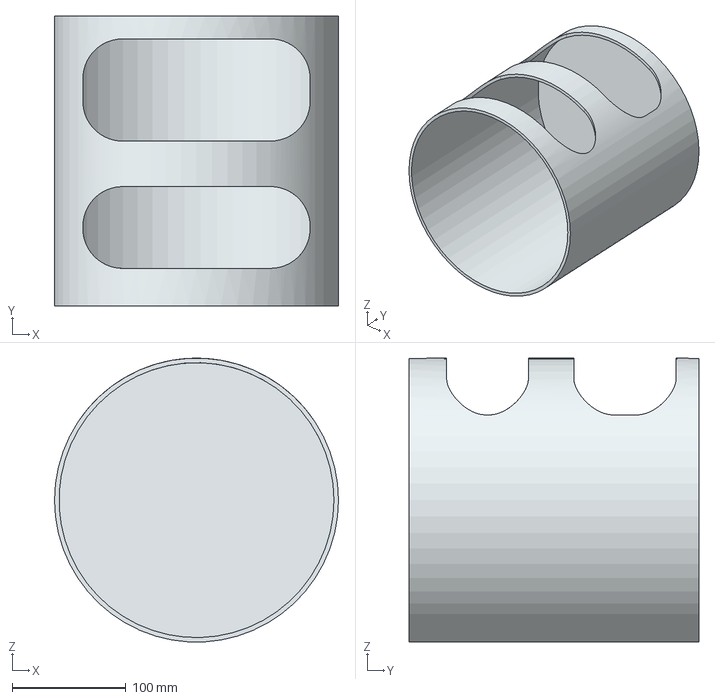
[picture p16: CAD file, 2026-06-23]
CAD/exports/headBody.step
250.0 x 255.0 x 249.8 mm

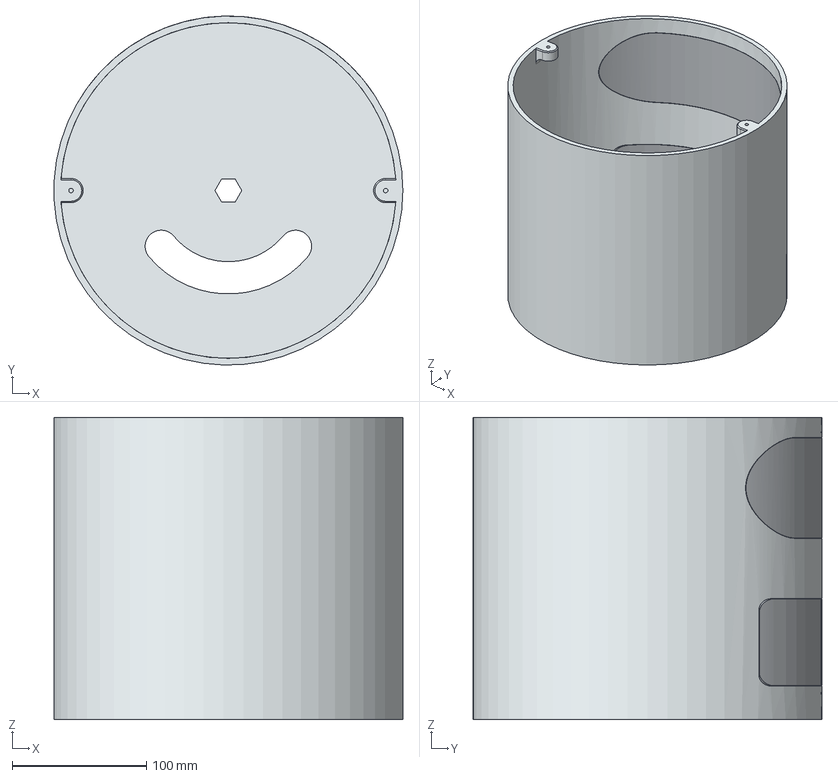
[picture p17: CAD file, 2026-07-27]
CAD/New/newBender2.0-Mid.step
259.8 x 259.9 x 225.0 mm
Mid-support
Mid

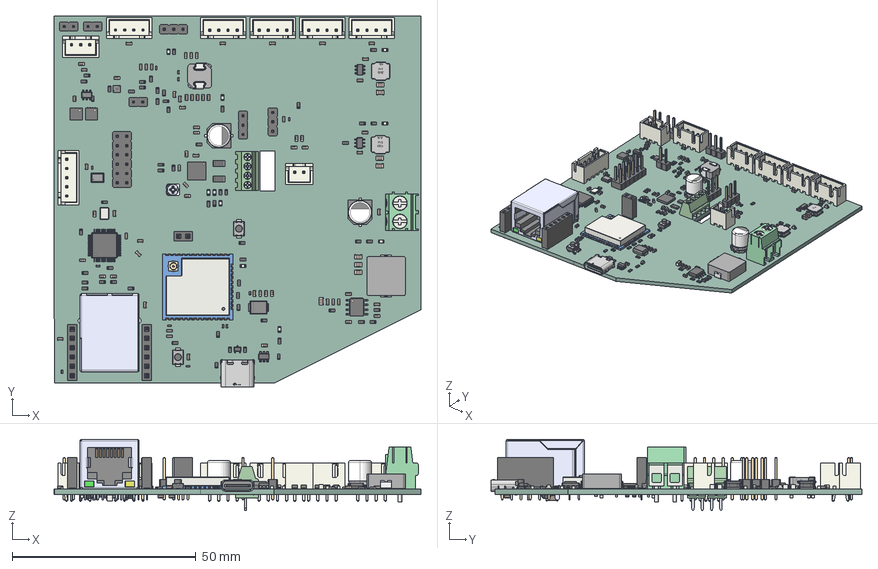
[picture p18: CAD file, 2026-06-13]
PCB/brain/BRAIN.step
100.0 x 101.0 x 19.5 mm
C_0603_1608Metric x 69
USB-C-SMD_TYPE-C-6PIN-2MD-073
R_0603_1608Metric x 57
QFN-28-1EP_5x5mm_Pitch0.5mm
CONN-TH_4P-P2.54_MX128-2.54-GN01-04P-CU-Y-A
SOT-23-6
SW_SPST_TS-1088-xR025 x 2
LED_0603_1608Metric x 10
C_0402_1005Metric x 18
JST_B4B_XH_A x 5
TSOT-23-6 x 2
C_0805_2012Metric x 8
IND-SMD_L7.1-W6.5-H3.0
JST_B2B_XH_A
IND-SMD_L11.5-W10.0-H4.0
PinSocket_1x06_P2.54mm_Vertical x 2
SOIC-8-1EP_3.9x4.9mm_P1.27mm_EP2.29x3mm
PinHeader_1x03_P254mm_Vertical x 3
PinHeader_1x02_P254mm_Vertical x 3
SOT-323_SC-70
TerminalBlock_Phoenix_PT-1,5-2-5.0-H_1x02_P5.00mm_Horizontal
JST_B3B_XH_A
RES-ADJ-SMD_3P-L3.8-W3.7_VGF39NCHXT
R_1206_3216Metric x 2
JST_B5B_XH_A
Crystal_SMD_3225-4Pin_3.2x2.5mm
ESP32-WROOM-32U
L_0603_1608Metric x 3
CAP-SMD_BD6.3-L6.6-W6.6-FD x 2
PinSocket_1x02_P2.54mm_Vertical
IND-SMD_L5.0-W5.0-H2.1 x 2
SOT-23-6_L2.9-W1.6-H1.5-LS2.8-P0.95
PinHeader_2x06_P254mm_Vertical
HR911105A_HR911105A
WSON-8_L2.0-W2.0-H0.8-P0.50
VSON_8_33x33mm_Pitch065mm_NexFET x 2
InvenSense_ICS-43434-6_3.5x2.65mm
LQFP-48_7x7mm_P0.5mm
SMB_L4.6-W3.6-LS5.3-RD
C_1206_3216Metric
brain_PCB

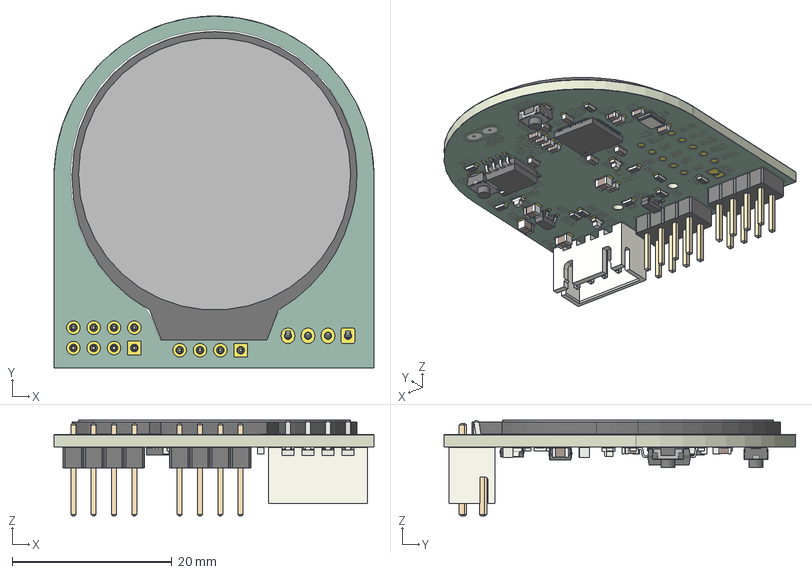
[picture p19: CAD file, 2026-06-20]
PCB/eye/mouth.step
40.0 x 44.0 x 12.0 mm
LH128R
C_0603_1608Metric x 14
R_0603_1608Metric x 11
LED_0603_1608Metric x 3
SOIC-8_5.3x5.3mm_P1.27mm
C_0805_2012Metric x 4
SW_SPST_TS-1088-xR025 x 2
SOT-23
PinHeader_2x04_P254mm_Vertical x 2
JST_B4B_XH_A
Crystal_SMD_3225-4Pin_3.2x2.5mm
SOT-23-5
QFN-56-1EP_7x7mm_P0.4mm_EP3.2x3.2mm
eye_copper
eye_silkscreen x 2
eye_soldermask x 2
eye_PCB

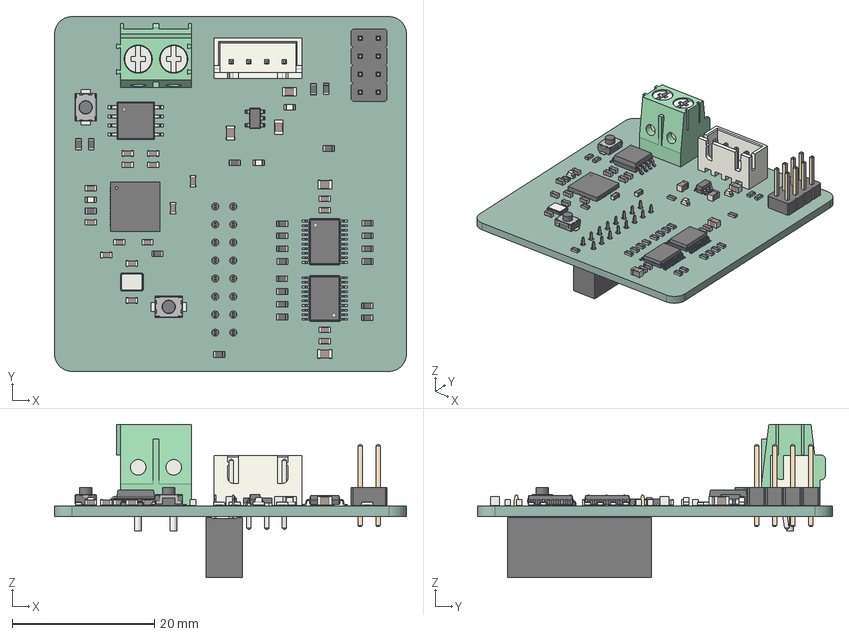
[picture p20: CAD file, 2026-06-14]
PCB/mouth/MOUTH.step
49.6 x 50.0 x 21.6 mm
R_0603_1608Metric x 23
PinHeader_2x04_P254mm_Vertical
C_0805_2012Metric x 5
C_0603_1608Metric x 17
SW_SPST_TS-1088-xR025 x 2
Crystal_SMD_3225-4Pin_3.2x2.5mm
QFN-56-1EP_7x7mm_P0.4mm_EP3.2x3.2mm
JST_B4B_XH_A
SOIC-8_5.3x5.3mm_P1.27mm
SOT-23-5
LED_0603_1608Metric x 3
SSOP-20_4.4x6.5mm_P0.65mm x 2
TerminalBlock_Phoenix_PT-1,5-2-5.0-H_1x02_P5.00mm_Horizontal
PinSocket_2x08_P2.54mm_Vertical
mouth_PCB

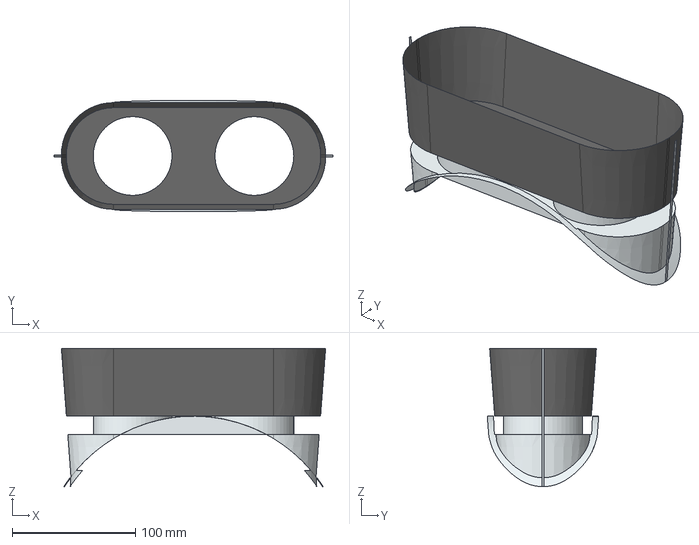
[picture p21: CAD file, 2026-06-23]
CAD/exports/visor.step
226.8 x 90.6 x 112.2 mm

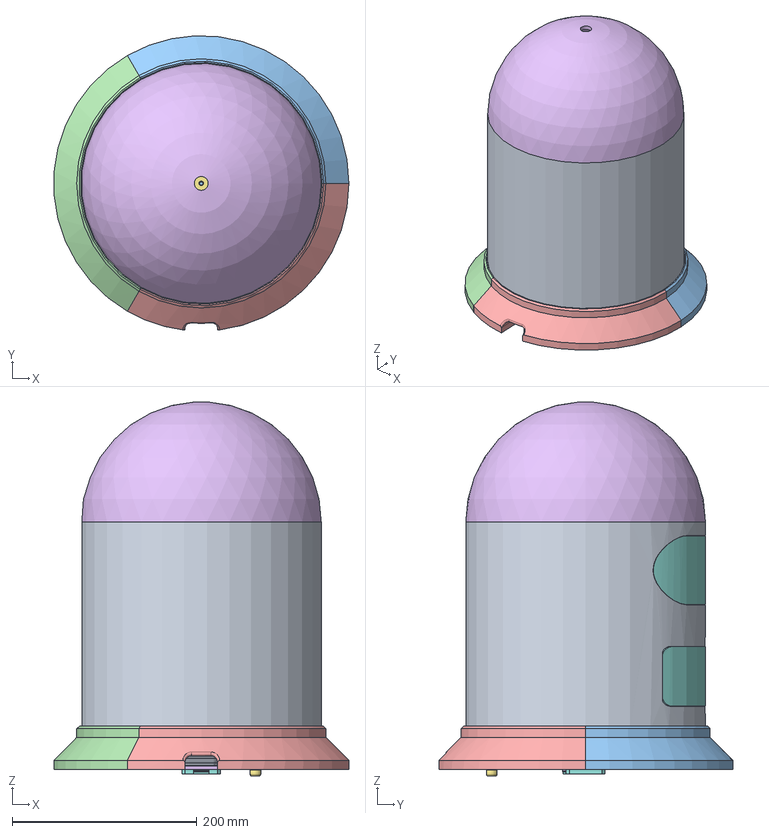
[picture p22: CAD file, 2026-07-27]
CAD/New/newBender2.0.FCStd
319.5 x 318.9 x 405.2 mm
Mid
Display
LENS
LENS2
VisorPlane
cover
MotorJoint
Bottom
Sheet_metal
Top_body
Axis
625ZZ_001
625ZZ_002
Sticker
Sticker001
Sticker002
Sticker003
Sticker004
Sticker005
Sticker006
Sticker007
Sticker008
Sticker009
Sticker010
Sticker011
Sticker012
Sticker013
Sticker014
Sticker015
Sticker016
Sticker017
Sticker018
Sticker019
Sticker020
Sticker021
Sticker022
Sticker023
Sticker024
Sticker025
Sticker026
Sticker027
Sticker028
Sticker029
Sticker030
Sticker031
Sticker032
Sticker033
Sticker034
Sticker035
Sticker036
Sticker037
C-440054-6
PCB
Conn_cover
M3x16-Vis
M3x16-Vis001
M3x16-Vis002
M3x16-Vis003
base-mid-2
base-mid-3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

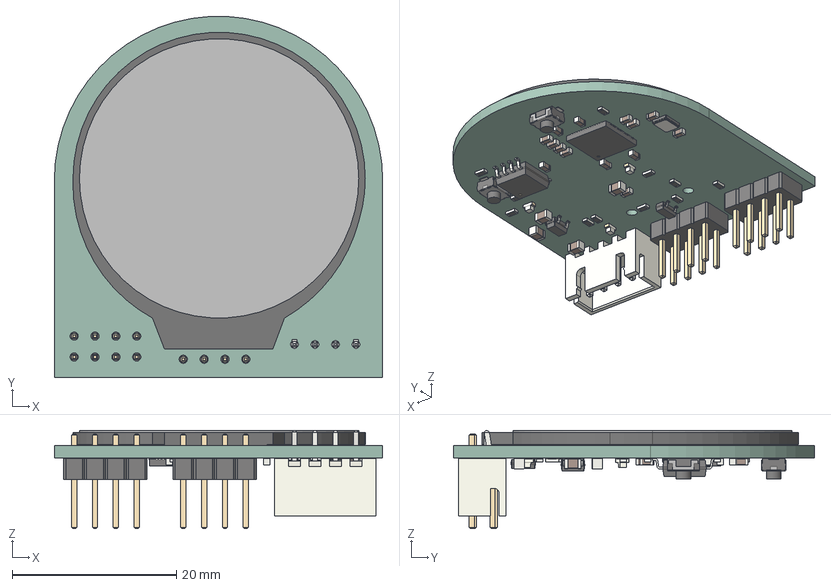
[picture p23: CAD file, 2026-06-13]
PCB/eye/EYE.step
40.0 x 44.0 x 12.0 mm
LH128R
C_0603_1608Metric x 14
R_0603_1608Metric x 11
LED_0603_1608Metric x 3
SOIC-8_5.3x5.3mm_P1.27mm
C_0805_2012Metric x 4
SW_SPST_TS-1088-xR025 x 2
SOT-23
PinHeader_2x04_P254mm_Vertical x 2
JST_B4B_XH_A
Crystal_SMD_3225-4Pin_3.2x2.5mm
SOT-23-5
QFN-56-1EP_7x7mm_P0.4mm_EP3.2x3.2mm
eye_PCB

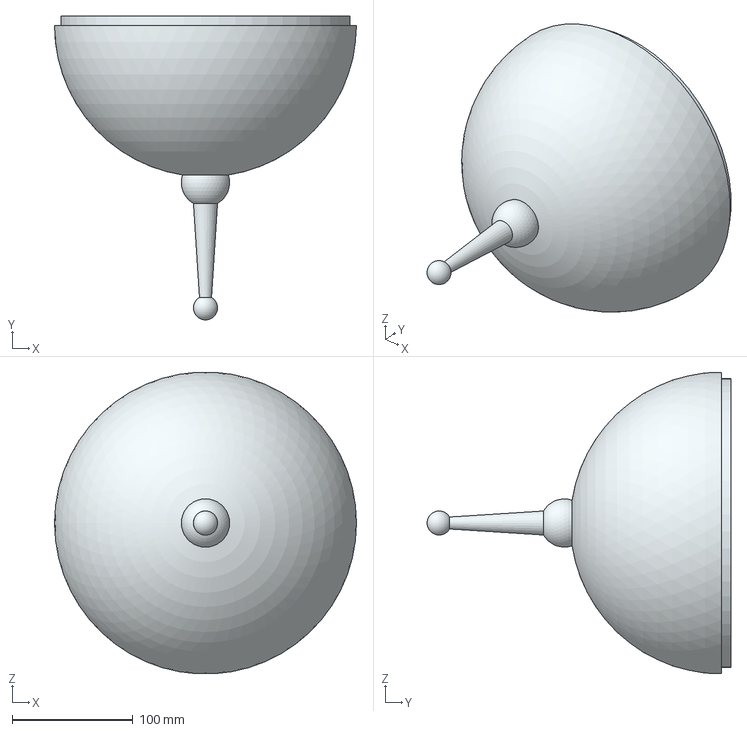
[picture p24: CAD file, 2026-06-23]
CAD/exports/headTop.step
250.0 x 251.5 x 249.6 mm

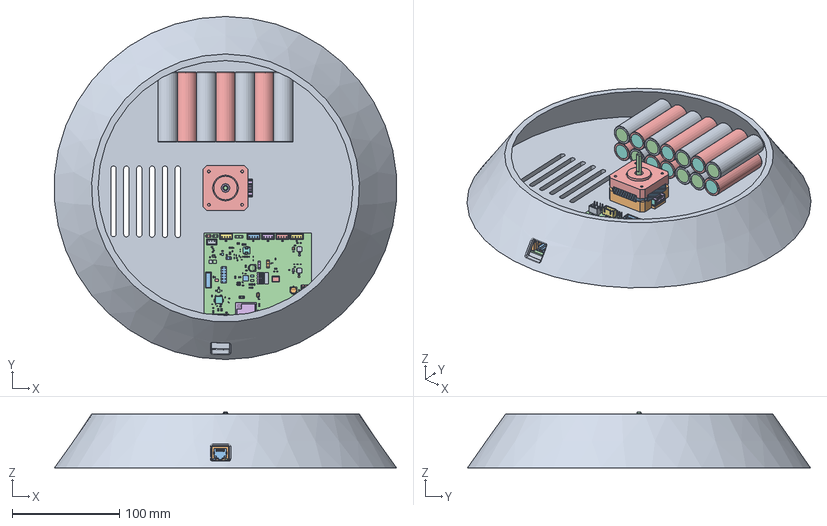
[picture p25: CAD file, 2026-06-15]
CAD/New bass bender.FCStd
319.1 x 320.0 x 51.8 mm
Cuerpo
Bottom
Sheet_metal
Axis
625ZZ_001
625ZZ_002
Sticker
Sticker001
Sticker002
Sticker003
Sticker004
Sticker005
Sticker006
Sticker007
Sticker008
Sticker009
Sticker010
Sticker011
Sticker012
Sticker013
Sticker014
Sticker015
Sticker016
Sticker017
Sticker018
Sticker019
Sticker020
Sticker021
Sticker022
Sticker023
Sticker024
Sticker025
Sticker026
Sticker027
Sticker028
Sticker029
Sticker030
Sticker031
Sticker032
Sticker033
Sticker034
Sticker035
Sticker036
Sticker037
Sticker038
Sticker039
Sticker040
Sticker041
Sticker042
Sticker043
Sticker044
Sticker045
Sticker046
Sticker047
Sticker048
Sticker049
Sticker050
Sticker051
Sticker052
Sticker053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

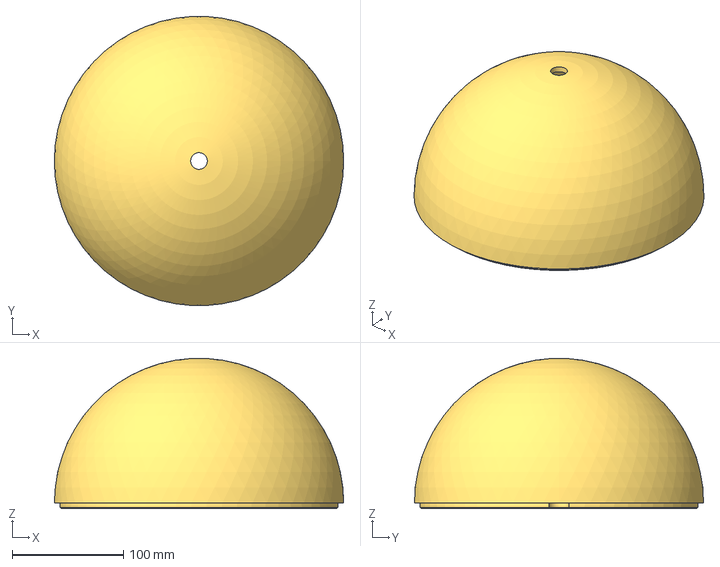
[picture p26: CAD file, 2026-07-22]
CAD/New/newBender2.0-cover.step
260.0 x 259.6 x 134.8 mm

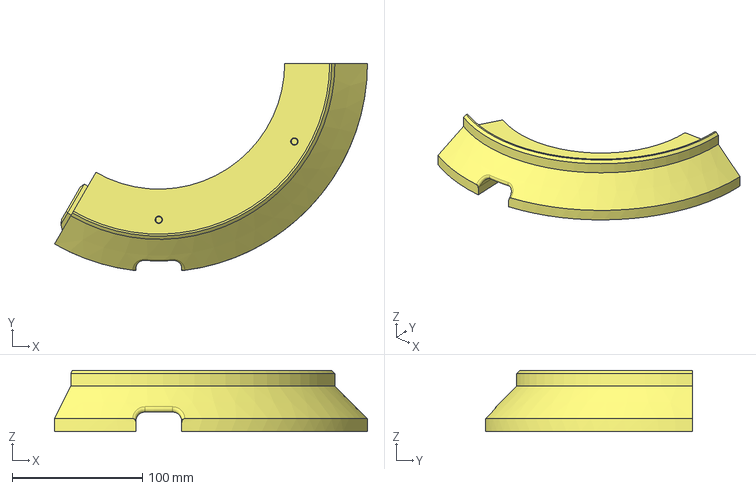
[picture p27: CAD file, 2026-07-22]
CAD/New/newBender2.0-base-mid-1.step
240.0 x 159.0 x 47.0 mm

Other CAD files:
CAD/ASM.FCStd
CAD/round display.FCStd
CAD/Bass bemder with a top lid.FCStd
CAD/New/newBender2.0-base-mid-3.step
CAD/Bass bemder without a top lid.FCStd
CAD/Head.FCStd
CAD/New/Plates.3mf
CAD/New/midHead.FCStd
CAD/New/newBender2.0-Feet.step
CAD/New/newBender2.0-MotorJoint.step
CAD/New/newBender2.0-Visor.step
CAD/New/newBender2.0-VisorPlane.step
CAD/New/newBender2.0-base-bottom.step
CAD/New/newBender2.0-base-mid-1Revolution003.step
CAD/New/newBender2.0-base-mid-2.step
CAD/New/newBender2.0-base-top.step
CAD/SarcasmOS.blend
CAD/tests.FCStd

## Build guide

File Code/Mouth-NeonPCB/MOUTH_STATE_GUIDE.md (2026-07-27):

# SarcasmOS mouth state guide

This guide explains every visual state supported by the 64x32 mouth display.
It is written for users, artists, and integrators who do not already know the
firmware or protocol.

## What a mouth state is

A state is the visual mode currently selected on the mouth. Examples include
`idle`, `thinking`, `speaking`, and `angry`. Each state has:

- a numeric protocol ID;
- a semantic meaning for the user;
- one or more native 64x32 artwork frames;
- a frame speed and playback rule;
- an event that should select it and another event that should replace it.

The mouth is a passive renderer. It does not listen to the microphone, inspect
the weather, read the battery, or decide that Bender is angry. The Brain or
another controller must send the corresponding state over ESP-NOW.

Receiving `SET_ANIMATION` (`0x20`) or `SET_EXPRESSION` (`0x21`) selects a
state. Receiving `STOP` (`0x23`) selects `asleep`. The display keeps the last
valid state until another command changes it. There is no automatic state
timeout in the mouth firmware.

## Two different meanings of “duration”

It is useful to separate these two timings:

1. **State lifetime** is how long the meaning remains active. This is
   event-driven. For example, `speaking` should normally last until playback
   ends. At firmware level it lasts indefinitely if no replacement arrives.
2. **Animation cycle** is how long the artwork takes to repeat while that
   state remains active. For example, `thinking` repeats every 864 ms.

Static states have one frame and therefore no visible animation cycle. Their
stored 1000 ms frame time is only a harmless asset-format value.

## State families

The 31 supported states fall into four practical families:

- **Activity states** explain what the assistant is doing: listening,
  thinking, using a tool, or speaking.
- **Expression states** convey attitude or emotion: neutral, sarcastic,
  angry, suspicious, and similar.
- **Gaze states** describe eye direction. Their mouth artwork deliberately
  stays neutral because looking left should not change the mouth.
- **Status/context states** report sleep, errors, battery condition, weather,
  or special modes.

`idle` and `neutral` look similar but mean different things. `idle` means the
assistant is ready and not doing work. `neutral` is a persistent facial
expression that can be restored after a temporary activity.

## Complete state reference

### Activity and conversation states

| ID | State | What it tells the user | Typical cause | Normal exit/lifetime | Mouth appearance and motion |
| ---: | --- | --- | --- | --- | --- |
| `0x00` | `idle` | The assistant is awake, ready, and not processing a request. | Boot has completed, a request has finished, or idle was explicitly requested. | Until recording, processing, an expression, an alert, or sleep begins. Firmware timeout: none. | Static pale-yellow Bender tooth grille. |
| `0x01` | `listening` | The robot is actively accepting input from the user. | Microphone capture or recording starts. | Until capture stops; normally followed by a thinking state. Firmware timeout: none. | A subtle scan moves across the resting grille; 8 frames, 192 ms each, 1.536 s cycle. |
| `0x02` | `thinking` | The request was received and the assistant is transcribing, planning, or generating an answer. It is not stuck merely because this animation repeats. | Speech transcription, LLM generation, tool planning, or Brain booting. | Until a tool starts, an answer is ready, speaking begins, or an error occurs. Firmware timeout: none. | Three paced thinking markers across the grille; 3 frames, 288 ms each, 864 ms cycle. |
| `0x03` | `thinking_audio` | Audio is specifically being uploaded, decoded, or transcribed. It is a faster version of thinking. | The web Workflow enters loading mode for an audio request. | Until audio processing completes or changes to ordinary thinking, speaking, or error. Firmware timeout: none. | Faster three-step marker motion; 3 frames, 192 ms each, 576 ms cycle. |
| `0x04` | `thinking_long` | Processing has taken longer than usual, but is still in progress. This is feedback, not itself an error. | In the web Workflow, thinking has continued for 3.8 seconds. | Until processing completes or fails. Firmware timeout: none. | Deliberately slower three-step thinking motion; 3 frames, 448 ms each, 1.344 s cycle. |
| `0x05` | `speaking` | The assistant is producing audible speech. | TTS playback starts or `mouth.talk` is requested. | Ideally while audio is audible, then restore the previous expression or `idle`. Firmware timeout: none. | A solid teeth-colored waveform replaces the internal tooth lines from roughly one-quarter to three-quarters of the screen. Eight amplitude frames are evaluated every 32 ms; the nominal up/down sequence is 448 ms. |
| `0x0a` | `tool` | The assistant is calling an external function such as weather, time, calendar, or device status. | A model tool/function call begins. | Until the tool returns; then resume thinking, show its resulting expression, speak, or show error. Firmware timeout: none. | Firm bar with a moving progress marker; 8 frames, 192 ms each, 1.536 s cycle. |

### Expression states

These states normally persist until explicitly changed or temporarily covered
by an activity/status state.

| ID | State | What it tells the user | Typical cause | Mouth appearance and motion |
| ---: | --- | --- | --- | --- |
| `0x06` | `happy_fake` | A deliberately artificial Bender-style happy face rather than a claim of genuine emotion. `happy` is an alias for this state. | An explicit happy-expression request or `set_expression("happy_fake")`. | Static small teeth-colored diamond in the current artwork. |
| `0x07` | `angry` | Anger, frustration, determination, or theatrical hostility. It should not imply a safety fault. | An explicit expression request or dialogue policy. | Static tight, clenched tooth grille. |
| `0x10` | `neutral` | No special emotion is being expressed. This is the safe expression fallback. | Explicit neutral request, expression reset, or restoration after a transient activity. | Static resting tooth grille. |
| `0x11` | `sarcastic` | Sarcasm, smugness, or a Bender-like smirk. | `mouth.smirk`, an explicit sarcastic request, or dialogue policy. | Static asymmetric raised smirk. |
| `0x12` | `suspicious` | Skepticism, doubt, or careful examination. | Explicit suspicious expression or a context-sensitive dialogue decision. | Static small skeptical dip/off-center mouth. |
| `0x13` | `tired` | Low energy or fatigue. This is an expression unless a separate power policy selects it. | Explicit tired expression or a future fatigue/inactivity policy. | Dim, shallow two-frame mouth; 640 ms per frame, 1.280 s cycle. |
| `0x14` | `surprised` | Surprise, shock, or sudden discovery. | Explicit surprised expression or a notable event. | Static small rounded open mouth. |
| `0x15` | `bored` | Disinterest or prolonged inactivity. | Explicit bored expression or a future idle-personality timer. | Static flat, minimally energetic mouth. |
| `0x16` | `dramatic` | Deliberate exaggeration for a theatrical response. | Explicit dramatic expression or dialogue policy. | Three sizes pulse forward and backward; 192 ms per step, 768 ms full ping-pong cycle. |
| `0x18` | `party` | Celebration, success, or party mode. | Explicit party request, event, or achievement. | Wide animated smile using accent colors; 6 frames, 144 ms each, 864 ms cycle. |

### Gaze and attention states

The names below mainly describe the eyes. The mouth uses a static neutral
grille in all five states. They exist as shared whole-face IDs so older or
simple controllers can send one synchronized state to all displays.

| ID | State | Typical cause | How long it should last |
| ---: | --- | --- | --- |
| `0x0b` | `left` | `eye.look.left` or tracking a target to the left. | Until gaze changes or tracking ends. |
| `0x0c` | `right` | `eye.look.right` or tracking a target to the right. | Until gaze changes or tracking ends. |
| `0x0d` | `up` | `eye.look.up` or tracking a target above. | Until gaze changes or tracking ends. |
| `0x0e` | `down` | `eye.look.down` or tracking a target below. | Until gaze changes or tracking ends. |
| `0x0f` | `center` | `eye.look.center`, loss of a tracked target, or gaze reset. | Until another gaze command. |

Changing gaze should not destroy a persistent mouth expression in a fully
composited face controller. The present one-byte protocol cannot represent
gaze and expression simultaneously, so the Brain should route gaze to the
eyes without replacing the mouth state where possible.

### Status, context, and environment states

| ID | State | What it tells the user | Typical cause | Normal exit/lifetime | Mouth appearance and motion |
| ---: | --- | --- | --- | --- | --- |
| `0x08` | `error` | A real operation or hardware/software action failed. It should not be used merely for an angry personality response. | Matrix/ESP-NOW initialization failure, failed tool call, invalid subsystem state, or explicit fault report. | Until recovery is confirmed or the user dismisses the error. Firmware timeout: none. | Slow red two-frame warning, 1.024 s per frame, 2.048 s cycle; deliberately avoids rapid flashing. |
| `0x09` | `asleep` | The face/display is sleeping or intentionally off. Protocol and Brain code may call this `sleep`. | `STOP`, explicit sleep, shutdown policy, or display-off request. | Until an explicit wake/new-animation command or reboot. | Fully black panel. |
| `0x17` | `watch` | The assistant is checking sensors, device status, or another live condition. | `robot_status`, sensor query, or monitoring action. | Until the status result is available. Firmware timeout: none. | Alert progress/scan in warm yellow; 9 frames, 192 ms each, 1.728 s cycle. |
| `0x19` | `battery_low` | Available battery energy is low and charging or shutdown may soon be needed. | Intended to come from a validated fuel-gauge threshold or explicit test; never from a guessed value. | Until the battery recovers above a hysteresis threshold, charging policy clears it, or sleep begins. Firmware timeout: none. | Dim sagging warning; 4 frames, 500 ms each, 2.000 s cycle. |
| `0x1a` | `sunny` | The most recent real weather result is sunny or clear. | Weather tool result containing clear/sunny conditions and a real temperature. | Until another expression/state replaces it; weather should be refreshed before treating it as current. | Static upturned grin with centered black temperature text. |
| `0x1b` | `rainy` | The most recent real weather result reports rain, drizzle, or showers. | Weather tool result containing rain-related conditions and a real temperature. | Until another expression/state replaces it. Firmware timeout: none. | Slow wave/downturn in rain color; 8 frames, 128 ms each, 1.024 s cycle, with centered black temperature text. |
| `0x1c` | `cloudy` | The most recent real weather result reports cloud or overcast conditions. | Weather tool result containing cloud/overcast conditions and a real temperature. | Until another expression/state replaces it. Firmware timeout: none. | Soft subdued oval; 3 frames, 480 ms each, 1.440 s cycle, with centered black temperature text. |
| `0x1d` | `stormy` | The most recent real weather result reports a storm or thunder. | Weather tool result containing thunder/storm conditions and a real temperature. | Until another expression/state replaces it. Firmware timeout: none. | Angular zigzag in storm color; 6 frames, 160 ms each, 960 ms cycle, with centered black temperature text. |
| `0x1e` | `snowy` | The most recent real weather result reports snow or sleet. | Weather tool result containing snow/sleet conditions and a real temperature. | Until another expression/state replaces it. Firmware timeout: none. | Sparse gentle snow-colored dots; 6 frames, 288 ms each, 1.728 s cycle, with centered black temperature text. |

Weather states must follow a real weather lookup. The system prompt explicitly
forbids inventing weather data, sensor values, battery readings, and completed
hardware actions.

`SET_PARAM` (`0x30`) with key `2` supplies temperature as a signed int8 number
of degrees Celsius. The usual two-character numeric forms, such as `30` and
`-5`, use equal-width character cells and therefore share the same horizontal
center. Wider valid values such as `-10` are measured and recentered rather
than clipped to two characters. The complete display text is `30°C`, `-5°C`,
and so on. The supported live-data range is `-127..127`; byte value `-128`
means “temperature unavailable” and hides the text. The value persists across
all five weather states until updated or cleared. The normal firmware starts
unavailable, while the local emulator/test firmware uses `30°C` as obvious
test data.

## Speaking intensity

`speaking` is the only state whose frame selection uses a live parameter.
`SET_PARAM` (`0x30`) with key `1` sets mouth intensity from `0` to `255`.

- Low values keep the waveform shallow.
- The default is `120`.
- Around `120`, the animation traverses its designed amplitude range.
- Higher values reach the largest frames sooner.
- The animation still repeats if the intensity is not updated, so the Brain
  should stop or replace `speaking` when audio ends.

The firmware redraws at most every 40 ms (25 frames per second), even though
the speaking asset phase advances in 32 ms steps. For live audio, the Brain
integration should send fresh intensity values at roughly 20-25 Hz and discard
stale queued values.

The current web UI uses audio RMS thresholds to decide when speech is audible:
voice starts around `0.028`, stops around `0.014`, and is held through pauses
for 180 ms. Those numbers belong to the web audio analyser; they are not
currently transmitted to the mouth as intensity automatically.

## State selection, replacement, and precedence

The desired face model contains three independent values:

1. a persistent expression, such as `sarcastic`;
2. a transient activity, such as `thinking` or `speaking`;
3. eye gaze/tracking.

A useful conceptual priority is:

1. display-off/`asleep`;
2. safety overlays such as `error` and `battery_low`;
3. active `speaking`;
4. other activity states;
5. the persistent expression.

The current mouth firmware does **not** store that stack. It stores one
animation ID, and the last valid command wins. It also does not remember which
expression to restore after speaking. The Brain must currently maintain those
values and send the correct restoration state. A future composited face
command could carry them independently.

## What is automatic today

There are three layers with different coverage:

### Mouth firmware

- Supports every ID `0x00` through `0x1e`.
- Starts in `idle`.
- Enters `error` automatically if ESP-NOW initialization fails after the
  matrix has initialized.
- Enters `asleep` when it receives `STOP`.
- Otherwise changes only when a valid command is received.
- Rejects unknown/out-of-range IDs rather than displaying arbitrary memory.

### Current Brain firmware

The Brain currently has seven high-level assistant states:
`booting`, `idle`, `listening`, `thinking`, `speaking`, `error`, and `sleep`.
It sends those over ESP-NOW, but its HTTP parser presently:

- collapses `thinking_audio` and `thinking_long` into `thinking`;
- maps `happy` to `idle`;
- maps `angry` to `error`;
- defaults unrecognized expressions to `idle`.

Therefore, all 31 animations are supported by the mouth and test tools, but
many are not yet reachable through the Brain's high-level HTTP API. Direct
protocol commands or future Brain state-machine work are needed for full
coverage. In particular, anger should eventually be kept distinct from a real
error.

### Workflow software

The CLI/backend uses:

- `thinking` during transcription, model generation, and tool planning;
- `tool` while a function call executes;
- `watch` while checking robot status;
- `error` when a tool call throws an exception;
- `speaking` while synthesizing/downloading/playing an answer;
- weather expressions after a real weather tool result;
- explicit expression states when a supported expression is requested.

The web front end adds `thinking_audio` for audio requests and marks thinking
as long after 3.8 seconds. These visual decisions currently affect the
software/web face; a bridge still needs to forward each transition to the
Brain for the physical mouth to mirror it.

## Timing and synchronization details

- The panel is redrawn every 40 ms, so a newly accepted state normally becomes
  visible on the next render update.
- ESP-NOW transport and Brain scheduling add their own latency. The integration
  target is under 100 ms from state decision to visible animation.
- Animation phase is based on the ESP32 millisecond clock plus an optional
  synchronization phase. Selecting a state does not reset its phase to frame
  zero, so synchronized displays can enter a repeating animation together.
- `SYNC` (`0x22`) changes phase; it does not change the selected state.
- Brightness changes do not change state or animation timing.
- The mouth's power-on brightness is `64/255`; the current Brain normally
  overrides it with `160/255` during startup.

## Typical conversation sequence

A complete voice request should look approximately like this:

```text
idle
  -> listening        microphone capture starts
  -> thinking_audio   audio upload/transcription
  -> thinking         model plans the answer
  -> tool             optional external tool call
  -> thinking         model uses the tool result
  -> speaking         audible response playback
  -> idle or saved persistent expression
```

If processing passes 3.8 seconds, `thinking_long` can replace the relevant
thinking state. Any failed stage may select `error`. A sleep request selects
`asleep` and remains there until a wake/new-state command.

## Names and aliases

| Name seen elsewhere | State used by the asset pack | Notes |
| --- | --- | --- |
| `happy` | `happy_fake` (`0x06`) | Protocol constant is currently named `kAnimHappy`. |
| `sleep` | `asleep` (`0x09`) | Protocol constant is currently named `kAnimSleep`. |
| `thinking-audio` | `thinking_audio` (`0x03`) | Hyphenated CSS name versus underscore protocol/asset name. |
| `thinking-long` | `thinking_long` (`0x04`) | Hyphenated CSS name versus underscore protocol/asset name. |
| `mouth.talk` | `speaking` (`0x05`) | Should be driven by audio intensity. |
| `mouth.smirk` | `sarcastic` (`0x11`) | Persistent expression intent. |

## For artists and testers

Run the desktop emulator from this directory:

```sh
./emulator.py
```

- Left/Right changes state.
- Space pauses both state cycling and animation frames.
- Up/Down selects a frame while paused.
- `E` opens the current native 64x32 frame in GIMP.
- `O` opens every frame of the current animation in GIMP.
- Overwriting an opened PPM automatically updates the shared asset pack and
  firmware header.
- In an animation edit folder, adding or deleting a one-based numbered PPM
  adds or removes that frame. Gaps are compacted automatically.

The authoritative artwork and timing live in
`assets/mouth_assets.json`. Both emulator and firmware use that file. Do not
edit `generated/mouth_assets.hpp` manually.

## Source files

- `assets/mouth_assets.json`: artwork, palette, frame order, and frame timing.
- `protocol.hpp`: mouth-side IDs and commands.
- `../Brain/components/mouth_espnow/include/display_protocol.h`: matching
  Brain-side protocol.
- `../Brain/main/main.c`: current high-level Brain state mapping.
- `../AI/Workflow/final1.py` and
  `../AI/Workflow/SarcasmOS-web/backend/bender_core.py`: Workflow state intent.
- `../AI/Workflow/SarcasmOS-web/app.js`: web thinking/audio timing.
- `MOUTH_STATES.md`: concise visual contract and intended composition model.

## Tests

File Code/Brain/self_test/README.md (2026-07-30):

# Brain PCB self-test firmware

This is a separate ESP-IDF application for bring-up and manufacturing checks of
the SarcasmOS brain PCB. It does not replace the production firmware in the
parent directory.

The report is printed through the ESP32-S3 native USB Serial/JTAG connection. It
tests:

- ESP32-S3 identity, flash, MAC address, and native USB serial output
- status LED and the charger/interrupt GPIO states
- `+5V` and `5VHP` regulator enable controls
- an I2C bus scan, including BQ25792 and MAX17049 detection
- MAX17049 version, cell voltage, and state-of-charge reads
- expected wired eye controller addresses (`0x30` and `0x31`)
- acknowledged ESP-NOW communication with the configured wireless mouth
- W5500 SPI communication through its version register
- an active Wi-Fi network scan (no credentials are required)
- I2S microphone samples and an optional short 440 Hz speaker tone

After the automatic checks, a menu-driven terminal interface remains available
on the same USB serial connection. It can:

- explicitly enable or disable the `+5V` and `5VHP` buck converters
- enable or disable charging through the BQ25792 active-low `CE` input
- scan for Wi-Fi networks, select one, enter its password, and connect
- report the connected SSID, channel, RSSI, IP address, and disconnect reason
- disconnect Wi-Fi
- run separate one-second speaker-tone and microphone-capture tests, with an
  interactive speaker level control
- address the I2C left eye, I2C right eye, or ESP-NOW mouth and visually cycle it
  through happy, error, and idle animations while checking its protocol status
- discover the two eyes by I2C protocol/role and the mouth by acknowledged
  ESP-NOW, select any combination with checkboxes, and repeatedly send any of
  the shared face states `0x00` through `0x1E`
- repeat the I2C, W5500, combined audio, and GPIO tests independently
- rerun the complete automatic test sequence

Wi-Fi credentials entered in the menu are kept in RAM only and are not saved to
flash. Password entry may be visible in the serial terminal.

The buck converters do not have voltage-sense or power-good signals connected
to the ESP32-S3. Their automatic result is therefore `WARN`: the firmware can
verify that the enable GPIO latched high, but a multimeter is required to verify
the actual output voltage.

The TMC2209 is deliberately left disabled so running the test cannot move a
connected motor.

## Build and flash

From `Code/Brain` with ESP-IDF loaded in the shell:

```sh
idf.py -C self_test set-target esp32s3
idf.py -C self_test build
idf.py -C self_test flash monitor
```

The USB monitor normally appears as `/dev/ttyACM0`. If automatic port detection
does not select it, add `-p /dev/ttyACM0` to the flash and monitor commands.

Optional tests and the audible tone can be changed with:

```sh
idf.py -C self_test menuconfig
```

Look under `SarcasmOS Brain self-test`.

Enter the station MAC printed by the mouth firmware in
`ESP-NOW mouth station MAC`. When the tester is not connected to an access
point, its configured ESP-NOW channel must match the mouth firmware's
`ESPNOW_CHANNEL`. An empty MAC safely makes the automatic wireless mouth result
`SKIP`.

## Manual terminal interface

When the initial report finishes, enter `h` to display the controls:

```text
brain-test> h
```

Input is echoed character by character as you type. Commands are single letters
or numbers. For example, enter `2` to disable the normal 5 V buck, `1` to enable
it again, `c` to select and connect to a Wi-Fi network, and `s` to show its
connection status and IP address. Use `p` for the speaker, `m` for the
microphone, `l`/`r` for the wired eyes, `o` for the wireless mouth, and `v` to
test all three displays. The complete automatic sequence is `x`.

The speaker screen generates a 440 Hz sine wave. Use Up/Down or `W`/`S` to
select levels from approximately 0.05 W through 3.2 W, then press Space or
Enter to play it. Levels above 1.5 W require a second confirmation. These
estimates assume a 4-ohm speaker, `AMP_VDD` selected to 5 V with JP1, and the
PCB's floating `GAIN_SLOT` pin (9 dB gain). The default is approximately
0.80 W. The 2.5 W setting is near the MAX98357A's 1% THD output limit; the
3.0 W and 3.2 W settings approach or enter clipping and are intended only for
brief hardware tests with suitably rated speakers. Do not exceed a speaker's
continuous rating, and do not connect two 4-ohm speakers in parallel.

Enter `f` for the interactive face display controller. It probes the left eye
at `0x30` and right eye at `0x31`, validates each Eye protocol-v2 role/status,
and requires an acknowledged ESP-NOW ping from the configured mouth. In the
target screen, move with the arrow keys or `W`/`S`, toggle checkboxes with
Space, and press Enter to continue. Unavailable displays cannot be selected;
use `R` to repeat discovery.

The state screen lists all shared Eye/Mouth animation IDs with descriptions,
ten at a time. Move with the arrow keys or `W`/`S` and press Enter (or Space)
to send the highlighted state to every selected target. The screen reports an
individual acknowledgment result for each display and remains open for
additional states. For a combined selection, the tester sends the tokenized
target to the selected eyes, waits for their matching active-token status,
then sends the same target/token and five-tick (200 ms) blend duration to the
mouth. Press `Q` or Escape to return to the main test menu.

If either selected Eye times out while reaching READY or activating the
committed state, the tester repeats the complete Eye transition once with a
fresh token before it sends the mouth command or reports the final result.

Enabling a buck only verifies the enable GPIO state. Measure the corresponding
rail before treating it as electrically validated.

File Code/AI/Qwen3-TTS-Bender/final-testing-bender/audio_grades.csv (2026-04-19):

group | audio_file | audio_path | rating | expected_rating | rating_diff | comment | graded_at
bender-voz3 | frase-1.wav | /home/pegoku/Media/Projects/Code/GitHub/sarcasmos/AI/Qwen3-TTS-Bender/final-testing-bender/bender-voz3/frase-1.wav | 5 | 3 | +2 |  | 2026-04-18T11:53:13
bender-voz3 | frase-2.wav | /home/pegoku/Media/Projects/Code/GitHub/sarcasmos/AI/Qwen3-TTS-Bender/final-testing-bender/bender-voz3/frase-2.wav | 7 | 3 | +4 |  | 2026-04-18T11:57:46
bender-voz3 | frase-3.wav | /home/pegoku/Media/Projects/Code/GitHub/sarcasmos/AI/Qwen3-TTS-Bender/final-testing-bender/bender-voz3/frase-3.wav | 6 |  |  |  | 2026-04-17T18:57:57
bender-voz3 | frase-4.wav | /home/pegoku/Media/Projects/Code/GitHub/sarcasmos/AI/Qwen3-TTS-Bender/final-testing-bender/bender-voz3/frase-4.wav | 4 |  |  |  | 2026-04-17T18:58:07
bender-voz3 | frase-5.wav | /home/pegoku/Media/Projects/Code/GitHub/sarcasmos/AI/Qwen3-TTS-Bender/final-testing-bender/bender-voz3/frase-5.wav | 7 | 3 | +4 |  | 2026-04-18T13:40:29
bender-voz3 | frase-6.wav | /home/pegoku/Media/Projects/Code/GitHub/sarcasmos/AI/Qwen3-TTS-Bender/final-testing-bender/bender-voz3/frase-6.wav | 2 |  |  |  | 2026-04-17T18:58:29
bender-voz3 | frase-7.wav | /home/pegoku/Media/Projects/Code/GitHub/sarcasmos/AI/Qwen3-TTS-Bender/final-testing-bender/bender-voz3/frase-7.wav | 2 |  |  |  | 2026-04-17T18:58:37
bender-voz3 | frase-8.wav | /home/pegoku/Media/Projects/Code/GitHub/sarcasmos/AI/Qwen3-TTS-Bender/final-testing-bender/bender-voz3/frase-8.wav | 7 | 3 | +4 |  | 2026-04-18T13:30:51
bender-voz3 | frase-9.wav | /home/pegoku/Media/Projects/Code/GitHub/sarcasmos/AI/Qwen3-TTS-Bender/final-testing-bender/bender-voz3/frase-9.wav | 5 | 3 | +2 |  | 2026-04-18T13:28:14
bender-voz3 | frase-10.wav | /home/pegoku/Media/Projects/Code/GitHub/sarcasmos/AI/Qwen3-TTS-Bender/final-testing-bender/bender-voz3/frase-10.wav | 3 |  |  |  | 2026-04-17T18:58:53
bender-voz3 | frase-11.wav | /home/pegoku/Media/Projects/Code/GitHub/sarcasmos/AI/Qwen3-TTS-Bender/final-testing-bender/bender-voz3/frase-11.wav | 5 | 3 | +2 | xa chillar, very good | 2026-04-18T13:40:55
bender-voz3 | frase-12.wav | /home/pegoku/Media/Projects/Code/GitHub/sarcasmos/AI/Qwen3-TTS-Bender/final-testing-bender/bender-voz3/frase-12.wav | 4 |  |  |  | 2026-04-17T18:59:08
bender-voz3 | frase-13.wav | /home/pegoku/Media/Projects/Code/GitHub/sarcasmos/AI/Qwen3-TTS-Bender/final-testing-bender/bender-voz3/frase-13.wav | 3 | 3 | +0 |  | 2026-04-18T13:38:43
bender-voz3 | frase-14.wav | /home/pegoku/Media/Projects/Code/GitHub/sarcasmos/AI/Qwen3-TTS-Bender/final-testing-bender/bender-voz3/frase-14.wav | 7 | 3 | +4 |  | 2026-04-18T13:33:03
bender-voz3 | frase-15.wav | /home/pegoku/Media/Projects/Code/GitHub/sarcasmos/AI/Qwen3-TTS-Bender/final-testing-bender/bender-voz3/frase-15.wav | 1 |  |  |  | 2026-04-17T18:59:34
bender-voz7 | frase-1.wav | /home/pegoku/Media/Projects/Code/GitHub/sarcasmos/AI/Qwen3-TTS-Bender/final-testing-bender/bender-voz7/frase-1.wav | 2 |  |  |  | 2026-04-17T19:00:00
bender-voz7 | frase-2.wav | /home/pegoku/Media/Projects/Code/GitHub/sarcasmos/AI/Qwen3-TTS-Bender/final-testing-bender/bender-voz7/frase-2.wav | 4 |  |  |  | 2026-04-17T19:00:11
bender-voz7 | frase-3.wav | /home/pegoku/Media/Projects/Code/GitHub/sarcasmos/AI/Qwen3-TTS-Bender/final-testing-bender/bender-voz7/frase-3.wav | 4 |  |  |  | 2026-04-17T19:00:24
bender-voz7 | frase-4.wav | /home/pegoku/Media/Projects/Code/GitHub/sarcasmos/AI/Qwen3-TTS-Bender/final-testing-bender/bender-voz7/frase-4.wav | 4 |  |  |  | 2026-04-17T19:00:34
bender-voz7 | frase-5.wav | /home/pegoku/Media/Projects/Code/GitHub/sarcasmos/AI/Qwen3-TTS-Bender/final-testing-bender/bender-voz7/frase-5.wav | 2 |  |  |  | 2026-04-17T19:00:42
bender-voz7 | frase-6.wav | /home/pegoku/Media/Projects/Code/GitHub/sarcasmos/AI/Qwen3-TTS-Bender/final-testing-bender/bender-voz7/frase-6.wav | 6 | 4 | +2 |  | 2026-04-18T13:30:44
bender-voz7 | frase-7.wav | /home/pegoku/Media/Projects/Code/GitHub/sarcasmos/AI/Qwen3-TTS-Bender/final-testing-bender/bender-voz7/frase-7.wav | 5 | 4 | +1 |  | 2026-04-18T13:34:18
bender-voz7 | frase-8.wav | /home/pegoku/Media/Projects/Code/GitHub/sarcasmos/AI/Qwen3-TTS-Bender/final-testing-bender/bender-voz7/frase-8.wav | 1 |  |  |  | 2026-04-17T19:00:54
bender-voz7 | frase-9.wav | /home/pegoku/Media/Projects/Code/GitHub/sarcasmos/AI/Qwen3-TTS-Bender/final-testing-bender/bender-voz7/frase-9.wav | 1 |  |  |  | 2026-04-17T19:00:58
bender-voz7 | frase-10.wav | /home/pegoku/Media/Projects/Code/GitHub/sarcasmos/AI/Qwen3-TTS-Bender/final-testing-bender/bender-voz7/frase-10.wav | 0 |  |  |  | 2026-04-17T19:01:03
bender-voz7 | frase-11.wav | /home/pegoku/Media/Projects/Code/GitHub/sarcasmos/AI/Qwen3-TTS-Bender/final-testing-bender/bender-voz7/frase-11.wav | 3 |  |  |  | 2026-04-17T19:01:13
bender-voz9 | frase-1.wav | /home/pegoku/Media/Projects/Code/GitHub/sarcasmos/AI/Qwen3-TTS-Bender/final-testing-bender/bender-voz9/frase-1.wav | 3 |  |  |  | 2026-04-17T19:01:28
bender-voz9 | frase-2.wav | /home/pegoku/Media/Projects/Code/GitHub/sarcasmos/AI/Qwen3-TTS-Bender/final-testing-bender/bender-voz9/frase-2.wav | 3 |  |  |  | 2026-04-17T19:01:39
bender-voz9 | frase-3.wav | /home/pegoku/Media/Projects/Code/GitHub/sarcasmos/AI/Qwen3-TTS-Bender/final-testing-bender/bender-voz9/frase-3.wav | 7 | 3 | +4 |  | 2026-04-18T11:59:16
bender-voz9 | frase-4.wav | /home/pegoku/Media/Projects/Code/GitHub/sarcasmos/AI/Qwen3-TTS-Bender/final-testing-bender/bender-voz9/frase-4.wav | 3 |  |  |  | 2026-04-17T19:01:57
bender-voz9 | frase-5.wav | /home/pegoku/Media/Projects/Code/GitHub/sarcasmos/AI/Qwen3-TTS-Bender/final-testing-bender/bender-voz9/frase-5.wav | 3 |  |  |  | 2026-04-17T19:02:01
bender-voz10 | frase-1.wav | /home/pegoku/Media/Projects/Code/GitHub/sarcasmos/AI/Qwen3-TTS-Bender/final-testing-bender/bender-voz10/frase-1.wav | 5 |  |  |  | 2026-04-17T19:02:16
bender-voz10 | frase-2.wav | /home/pegoku/Media/Projects/Code/GitHub/sarcasmos/AI/Qwen3-TTS-Bender/final-testing-bender/bender-voz10/frase-2.wav | 4 |  |  |  | 2026-04-17T19:02:20
bender-voz10 | frase-3.wav | /home/pegoku/Media/Projects/Code/GitHub/sarcasmos/AI/Qwen3-TTS-Bender/final-testing-bender/bender-voz10/frase-3.wav | 7 |  |  |  | 2026-04-17T19:02:31
bender-voz10 | frase-4.wav | /home/pegoku/Media/Projects/Code/GitHub/sarcasmos/AI/Qwen3-TTS-Bender/final-testing-bender/bender-voz10/frase-4.wav | 7 |  |  |  | 2026-04-17T19:02:41
bender-voz10 | frase-5.wav | /home/pegoku/Media/Projects/Code/GitHub/sarcasmos/AI/Qwen3-TTS-Bender/final-testing-bender/bender-voz10/frase-5.wav | 7 |  |  |  | 2026-04-17T19:02:50
bender-voz10 | frase-6.wav | /home/pegoku/Media/Projects/Code/GitHub/sarcasmos/AI/Qwen3-TTS-Bender/final-testing-bender/bender-voz10/frase-6.wav | 5 | 6 | -1 |  | 2026-04-18T13:41:12
bender-voz10 | frase-7.wav | /home/pegoku/Media/Projects/Code/GitHub/sarcasmos/AI/Qwen3-TTS-Bender/final-testing-bender/bender-voz10/frase-7.wav | 5 |  |  |  | 2026-04-17T19:03:09
bender-voz10 | frase-8.wav | /home/pegoku/Media/Projects/Code/GitHub/sarcasmos/AI/Qwen3-TTS-Bender/final-testing-bender/bender-voz10/frase-8.wav | 2 |  |  |  | 2026-04-17T19:03:13
bender-voz11 | frase-1.wav | /home/pegoku/Media/Projects/Code/GitHub/sarcasmos/AI/Qwen3-TTS-Bender/final-testing-bender/bender-voz11/frase-1.wav | 8 |  |  |  | 2026-04-17T19:03:25
bender-voz11 | frase-2.wav | /home/pegoku/Media/Projects/Code/GitHub/sarcasmos/AI/Qwen3-TTS-Bender/final-testing-bender/bender-voz11/frase-2.wav | 4 | 6 | -2 | mejicano | 2026-04-18T13:46:16
bender-voz11 | frase-3.wav | /home/pegoku/Media/Projects/Code/GitHub/sarcasmos/AI/Qwen3-TTS-Bender/final-testing-bender/bender-voz11/frase-3.wav | 5 | 6 | -1 |  | 2026-04-18T12:01:11
bender-voz11 | frase-4.wav | /home/pegoku/Media/Projects/Code/GitHub/sarcasmos/AI/Qwen3-TTS-Bender/final-testing-bender/bender-voz11/frase-4.wav | 4 | 6 | -2 |  | 2026-04-18T13:42:02
bender-voz11 | frase-5.wav | /home/pegoku/Media/Projects/Code/GitHub/sarcasmos/AI/Qwen3-TTS-Bender/final-testing-bender/bender-voz11/frase-5.wav | 7 |  |  |  | 2026-04-17T19:04:03
bender-voz11 | frase-6.wav | /home/pegoku/Media/Projects/Code/GitHub/sarcasmos/AI/Qwen3-TTS-Bender/final-testing-bender/bender-voz11/frase-6.wav | 5 | 6 | -1 |  | 2026-04-18T13:34:45
bender-voz11 | frase-7.wav | /home/pegoku/Media/Projects/Code/GitHub/sarcasmos/AI/Qwen3-TTS-Bender/final-testing-bender/bender-voz11/frase-7.wav | 7 |  |  |  | 2026-04-17T19:04:26
bender-voz11 | frase-8.wav | /home/pegoku/Media/Projects/Code/GitHub/sarcasmos/AI/Qwen3-TTS-Bender/final-testing-bender/bender-voz11/frase-8.wav | 5 |  |  |  | 2026-04-17T19:04:31
bender-voz11 | frase-9.wav | /home/pegoku/Media/Projects/Code/GitHub/sarcasmos/AI/Qwen3-TTS-Bender/final-testing-bender/bender-voz11/frase-9.wav | 4 |  |  |  | 2026-04-17T19:04:34
bender-voz11 | frase-10.wav | /home/pegoku/Media/Projects/Code/GitHub/sarcasmos/AI/Qwen3-TTS-Bender/final-testing-bender/bender-voz11/frase-10.wav | 5 |  |  |  | 2026-04-17T19:04:38
bender-voz11 | frase-11.wav | /home/pegoku/Media/Projects/Code/GitHub/sarcasmos/AI/Qwen3-TTS-Bender/final-testing-bender/bender-voz11/frase-11.wav | 6 |  |  |  | 2026-04-17T19:04:48
bender-voz11 | frase-12.wav | /home/pegoku/Media/Projects/Code/GitHub/sarcasmos/AI/Qwen3-TTS-Bender/final-testing-bender/bender-voz11/frase-12.wav | 5 |  |  |  | 2026-04-17T19:04:53
bender-voz11 | frase-13.wav | /home/pegoku/Media/Projects/Code/GitHub/sarcasmos/AI/Qwen3-TTS-Bender/final-testing-bender/bender-voz11/frase-13.wav | 5 |  |  |  | 2026-04-17T19:05:00
bender-voz11 | frase-14.wav | /home/pegoku/Media/Projects/Code/GitHub/sarcasmos/AI/Qwen3-TTS-Bender/final-testing-bender/bender-voz11/frase-14.wav | 5 |  |  |  | 2026-04-17T19:05:04
bender-voz11 | frase-15.wav | /home/pegoku/Media/Projects/Code/GitHub/sarcasmos/AI/Qwen3-TTS-Bender/final-testing-bender/bender-voz11/frase-15.wav | 7 |  |  |  | 2026-04-17T19:05:14
bender-voz11 | frase-16.wav | /home/pegoku/Media/Projects/Code/GitHub/sarcasmos/AI/Qwen3-TTS-Bender/final-testing-bender/bender-voz11/frase-16.wav | 8 |  |  |  | 2026-04-17T19:05:30
bender-voz11 | frase-17.wav | /home/pegoku/Media/Projects/Code/GitHub/sarcasmos/AI/Qwen3-TTS-Bender/final-testing-bender/bender-voz11/frase-17.wav | 8 |  |  | seems like all of this ones get cut at the end | 2026-04-17T19:05:47
bender-voz11 | frase-18.wav | /home/pegoku/Media/Projects/Code/GitHub/sarcasmos/AI/Qwen3-TTS-Bender/final-testing-bender/bender-voz11/frase-18.wav | 8 |  |  |  | 2026-04-17T19:05:53
bender-voz11 | frase-19.wav | /home/pegoku/Media/Projects/Code/GitHub/sarcasmos/AI/Qwen3-TTS-Bender/final-testing-bender/bender-voz11/frase-19.wav | 6 |  |  |  | 2026-04-17T19:08:39
bender-voz11 | frase-20.wav | /home/pegoku/Media/Projects/Code/GitHub/sarcasmos/AI/Qwen3-TTS-Bender/final-testing-bender/bender-voz11/frase-20.wav | 1 |  |  |  | 2026-04-17T19:08:47
bender-voz11 | frase-21.wav | /home/pegoku/Media/Projects/Code/GitHub/sarcasmos/AI/Qwen3-TTS-Bender/final-testing-bender/bender-voz11/frase-21.wav | 4 |  |  |  | 2026-04-17T19:08:59
bender-voz11 | frase-22.wav | /home/pegoku/Media/Projects/Code/GitHub/sarcasmos/AI/Qwen3-TTS-Bender/final-testing-bender/bender-voz11/frase-22.wav | 5 | 6 | -1 |  | 2026-04-18T11:55:58
bender-voz11 | frase-23.wav | /home/pegoku/Media/Projects/Code/GitHub/sarcasmos/AI/Qwen3-TTS-Bender/final-testing-bender/bender-voz11/frase-23.wav | 6 |  |  |  | 2026-04-17T19:13:46
bender-voz11 | frase-24.wav | /home/pegoku/Media/Projects/Code/GitHub/sarcasmos/AI/Qwen3-TTS-Bender/final-testing-bender/bender-voz11/frase-24.wav | 6 |  |  |  | 2026-04-17T19:13:54
bender-voz12 | frase-1.wav | /home/pegoku/Media/Projects/Code/GitHub/sarcasmos/AI/Qwen3-TTS-Bender/final-testing-bender/bender-voz12/frase-1.wav | 8 |  |  |  | 2026-04-17T19:14:11
bender-voz12 | frase-2.wav | /home/pegoku/Media/Projects/Code/GitHub/sarcasmos/AI/Qwen3-TTS-Bender/final-testing-bender/bender-voz12/frase-2.wav | 8 |  |  |  | 2026-04-17T19:14:23
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

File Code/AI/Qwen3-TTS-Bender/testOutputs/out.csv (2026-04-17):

test-bender-voz10.wav
test-bender-voz11.wav
test-bender-voz12.wav
test-bender-voz13.wav
test-bender-voz14.wav
test-bender-voz15.wav
test-bender-voz16.wav
test-bender-voz17.wav
test-bender-voz19.wav
test-bender-voz20.wav
test-bender-voz24.wav
test-bender-voz25.wav
test-bender-voz26.wav
test-bender-voz28.wav
test-bender-voz29.wav
test-bender-voz30.wav
test-bender-voz32.wav
test-bender-voz33.wav
test-bender-voz35.wav
test-bender-voz38.wav
test-bender-voz3.wav
test-bender-voz40.wav
test-bender-voz41.wav
test-bender-voz43.wav
test-bender-voz45.wav
test-bender-voz46.wav
test-bender-voz47.wav
test-bender-voz49.wav
test-bender-voz51.wav
test-bender-voz52.wav
test-bender-voz53.wav
test-bender-voz54.wav
test-bender-voz55.wav
test-bender-voz56.wav
test-bender-voz58.wav
test-bender-voz60.wav
test-bender-voz61.wav
test-bender-voz62.wav
test-bender-voz63.wav
test-bender-voz66.wav
test-bender-voz70.wav
test-bender-voz73.wav
test-bender-voz74.wav
test-bender-voz76.wav
test-bender-voz77.wav
test-bender-voz78.wav
test-bender-voz79.wav
test-bender-voz7.wav
test-bender-voz82.wav
test-bender-voz9.wav

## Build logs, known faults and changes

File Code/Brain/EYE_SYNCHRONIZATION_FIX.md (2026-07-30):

# Eye synchronization implementation specification

## Problem and root cause

The Brain already sends the same animation and transition token to the left and
right Eye in immediate succession. At 400 kHz I2C, the transmission skew is
small and is not the source of a visibly long offset.

The Eye firmware does not use the token as a start barrier. Each Eye currently:

1. receives `SET_ANIMATION` independently;
2. asks its locally running animation to exit;
3. finishes that exit from its own current frame and direction; and
4. immediately activates the pending animation on its own local clock.

This happens in `src/main.cpp`: `request_animation()` calls
`eye_playback::request_exit()`, and `update_animation_playback()` calls
`activate_animation()` as soon as that individual Eye finishes. The two Eyes
can be at different outgoing frames, and one main loop can be occupied sending
a 240x240 frame to its display. Consequently, one Eye may activate well before
the other. `kCmdSync` currently does nothing. The 13-byte status and transition
token let Brain observe the difference after it occurs; they do not prevent it.

Do not try to fix this by adding an arbitrary delay between Brain's two
`SET_ANIMATION` writes. That only changes which Eye is late. Likewise, polling
faster cannot synchronize activation that has already happened.

## Required behavior

- Both Eyes may finish their outgoing animations independently.
- An Eye that finishes first must hold its legal exit frame and report READY;
  it must not activate the destination yet.
- Brain waits until every requested Eye is READY.
- Brain then commits both Eyes with a short future start delay.
- Both Eyes activate the destination/token at that deadline and start at frame
  zero. Expected visible skew should be at most one I2C transaction plus local
  scheduling jitter, preferably below 1 ms and never more than one frame.
- A missing Eye must not leave the other Eye frozen forever.

## Eye firmware changes

### 1. Add an armed/ready transition phase

Extend `eye_transition::State` in `include/animation_transition.hpp` with a
ready/armed state. A queued destination still has `pending_animation` and
`pending_token`, but reaching the legal exit boundary must set `ready = true`
instead of calling `activate_pending()`.

In `update_animation_playback()`:

- when `eye_playback::advance()` says the outgoing animation is complete and a
  pending destination exists, set READY and hold the final legal exit frame;
- do not advance the outgoing playback again while READY;
- do not call `activate_animation()` until a matching commit is armed and its
  deadline has arrived.

A new request with a newer token replaces the pending destination and clears
READY/commit state. Repeating the identical animation/token remains idempotent.
A request for the already-active animation with a new token must be defined
explicitly: preferably treat it as an immediately READY restart so Brain can
resynchronize two Eyes that have drifted while showing the same state.

### 2. Report READY in the existing status

Use bit 3 of status byte 11 (`playback_flags`) as
`EYE_PROTOCOL_FLAG_READY`. Preserve the existing meanings:

- bit 0: pending;
- bit 1: exiting;
- bit 2: activated/no pending;
- bit 3: ready at the outgoing exit barrier.

While READY, status must continue reporting the outgoing animation/token as
active and the requested destination/token as pending. Update the status
snapshot immediately when READY changes.

### 3. Implement `CMD_SYNC` as the commit operation

Use a versioned payload so malformed or stale commits are rejected:

```text
CMD_SYNC payload (4 bytes)
byte 0: transition token
byte 1: start delay, little-endian milliseconds low byte
byte 2: start delay, little-endian milliseconds high byte
byte 3: flags; must currently be zero
```

Accept the command only when:

- a pending destination exists;
- the Eye is READY;
- the supplied token equals `pending_token`; and
- the delay is within a bounded range, for example 10-250 ms.

Record the I2C STOP reception timestamp in the IRQ handler and calculate the
deadline from that timestamp, not from the later `parse_command()` call. This
prevents a display transfer from adding different parsing delays on the two
boards. A stale/wrong token must leave the current transition untouched and set
an error visible in status.

Start with a 50 ms delay. That is long enough for both RP2040 main loops to
finish parsing the sequential commit packets before either deadline.

### 4. Make the visible first frame honor the deadline

At the commit deadline:

- atomically make the pending animation/token active;
- clear pending, READY, and commit state;
- reset playback to frame zero;
- set both `frame_started_ms` and `animation_started_ms` to the scheduled
  deadline, not the time at which the main loop happened to notice it;
- render frame zero immediately.

Avoid beginning a full display transfer when an armed deadline is closer than
the measured worst-case `draw_eye()` duration. Otherwise one Eye can be trapped
inside an SPI transfer while the other begins. If a deadline is nevertheless
noticed late, derive playback position from elapsed time since the scheduled
deadline so both Eyes converge to the same frame rather than permanently
retaining the offset.

Do not add an arbitrary remote uptime directly to the frame index. The only
time reference here is the locally calculated commit deadline.

### 5. Timeout and emergency behavior

- If READY is reached but no valid commit arrives, hold for a bounded timeout
  and then either cancel safely or remain on the outgoing exit pose while
  reporting an error. Do not silently activate early.
- Provide a force/immediate flag only if emergency states need to skip graceful
  exit. Even emergency changes should be armed on both Eyes first and committed
  with a small future delay.
- Watchdog servicing must continue while READY and while waiting for a commit.

## Brain changes required after Eye support exists

Production `main/main.c` and `self_test/main/main.c` must then use a two-phase
barrier:

1. send the same `SET_ANIMATION {animation, token, mouth_duration}` to both
   selected Eyes;
2. poll the direct 13-byte status until each sent Eye reports pending
   animation/token plus `EYE_PROTOCOL_FLAG_READY`;
3. send `CMD_SYNC {token, 50 ms, flags=0}` to both Eyes back-to-back while
   holding the I2C mutex for the pair;
4. poll until both report the destination/token active with no pending state;
5. release the mouth transition at the intended coordinated point.

If one Eye fails or times out, commit the READY Eye rather than leaving it
stuck, mark the transition degraded, and log the missing role. The self-test
face controller must use the same algorithm so it tests production behavior.

Until the Eye firmware implements READY plus commit, Brain cannot guarantee a
simultaneous start without discarding the graceful-exit behavior.

## Verification

Add host tests for at least these cases:

- Eyes begin on different frames/directions and reach READY at different times;
- neither activates before a matching commit;
- wrong-token and duplicate commits are harmless;
- both activate frame zero at the scheduled deadline;
- a late main-loop wake-up catches up to the correct common frame;
- replacement requests clear the old READY/commit state;
- same-animation/new-token requests can resynchronize drift;
- one absent Eye times out without freezing the present Eye.

On hardware, expose the activation event on the RP2040 LED or a spare test GPIO
and capture both boards with a logic analyzer. Measure I2C commit STOP-to-GPIO
latency and left/right GPIO skew. Also record Brain's send/READY/commit logs and
confirm the visible frame indices remain equal after activation.

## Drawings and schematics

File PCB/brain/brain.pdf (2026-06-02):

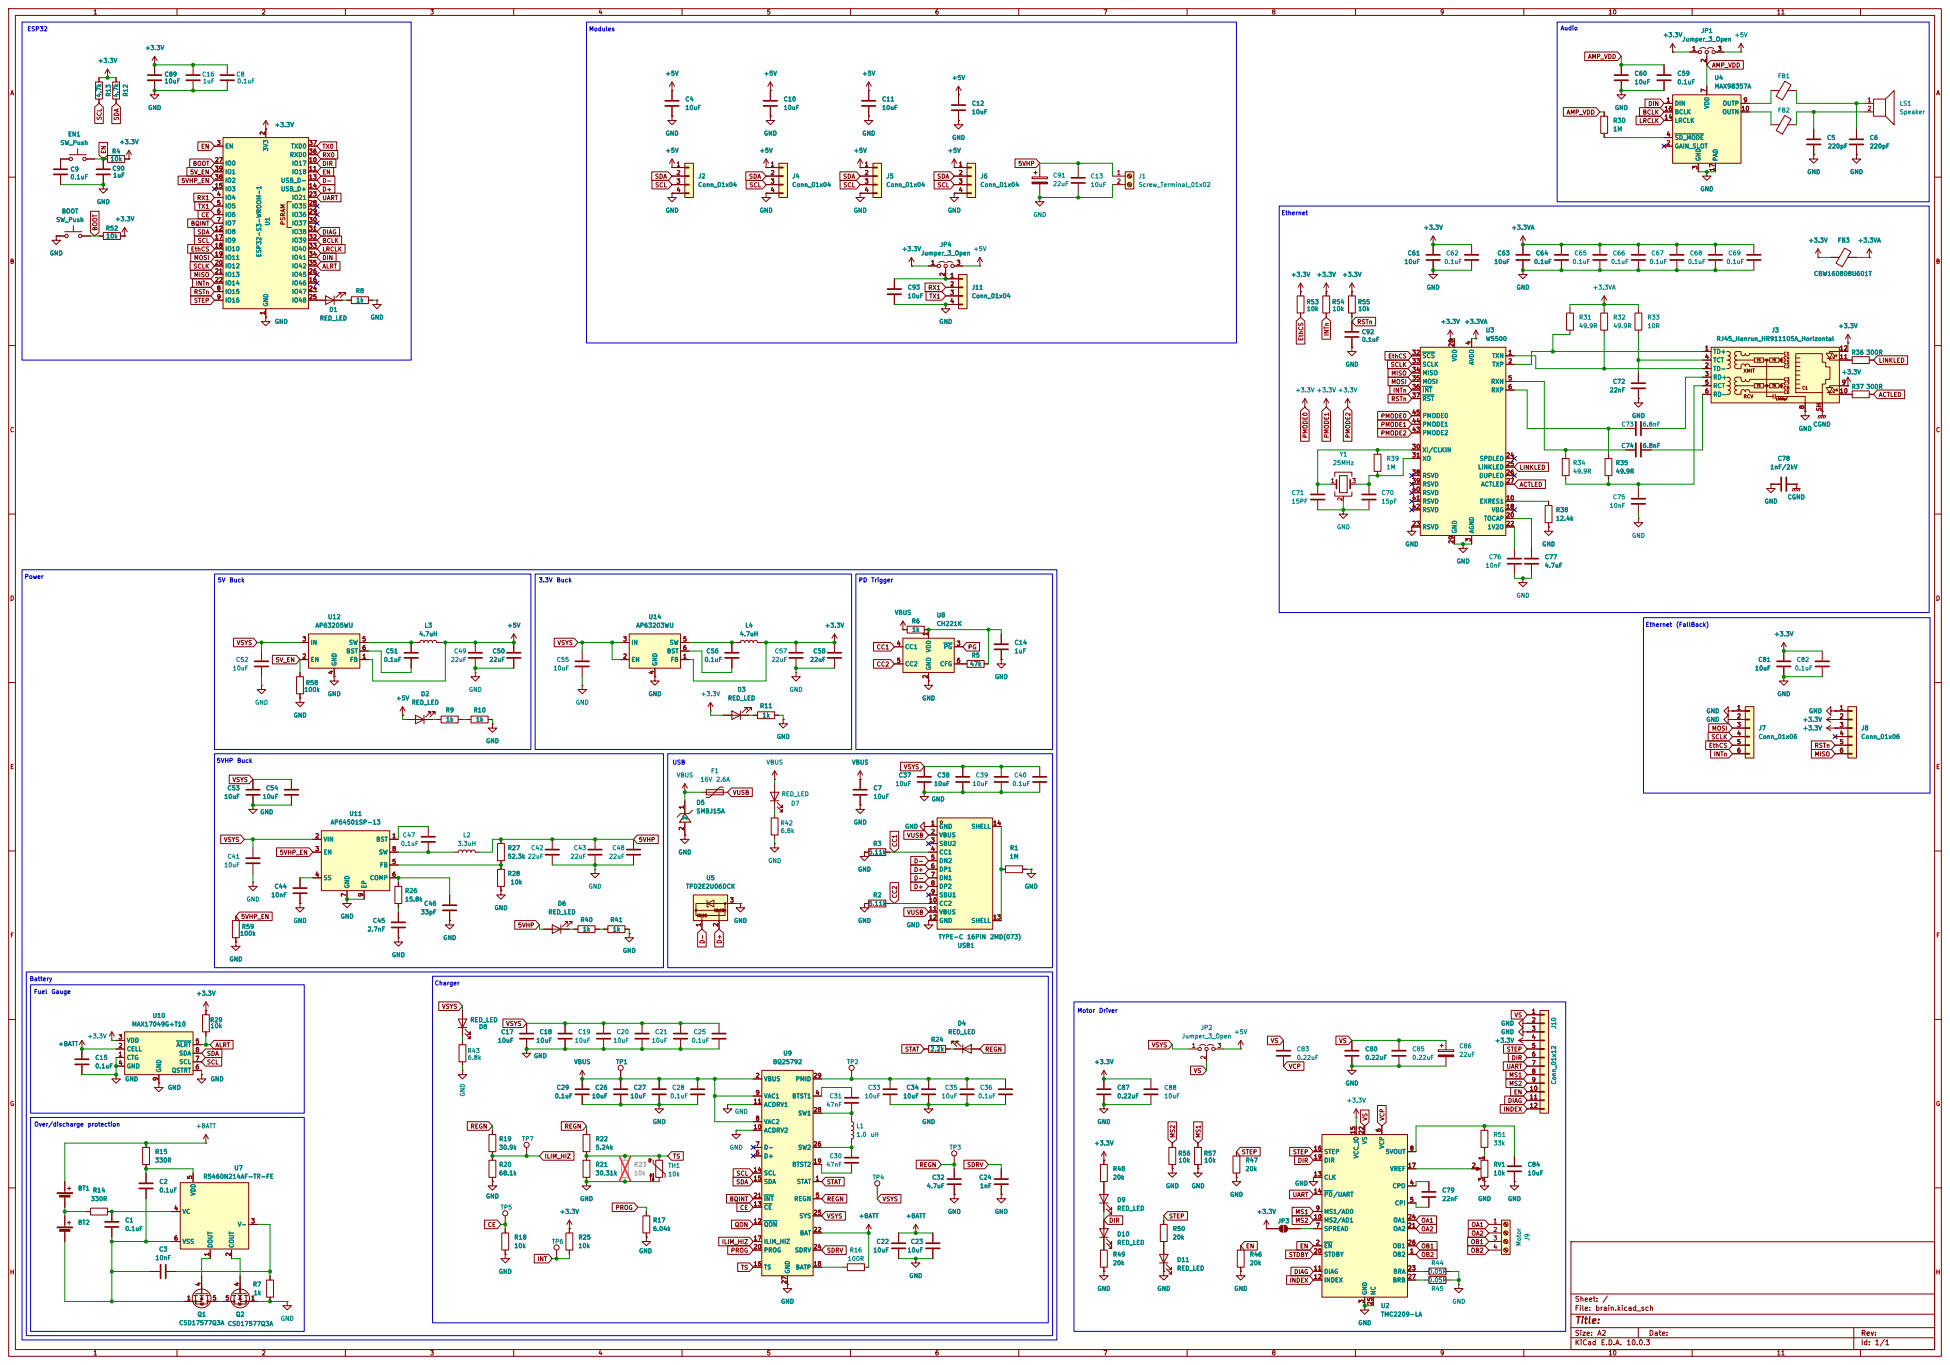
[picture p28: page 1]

5 Q1 CSD17577Q3A

Size: A2 | Rev:
KiCad E.D.A. 10.0.3 | Id: 1/1

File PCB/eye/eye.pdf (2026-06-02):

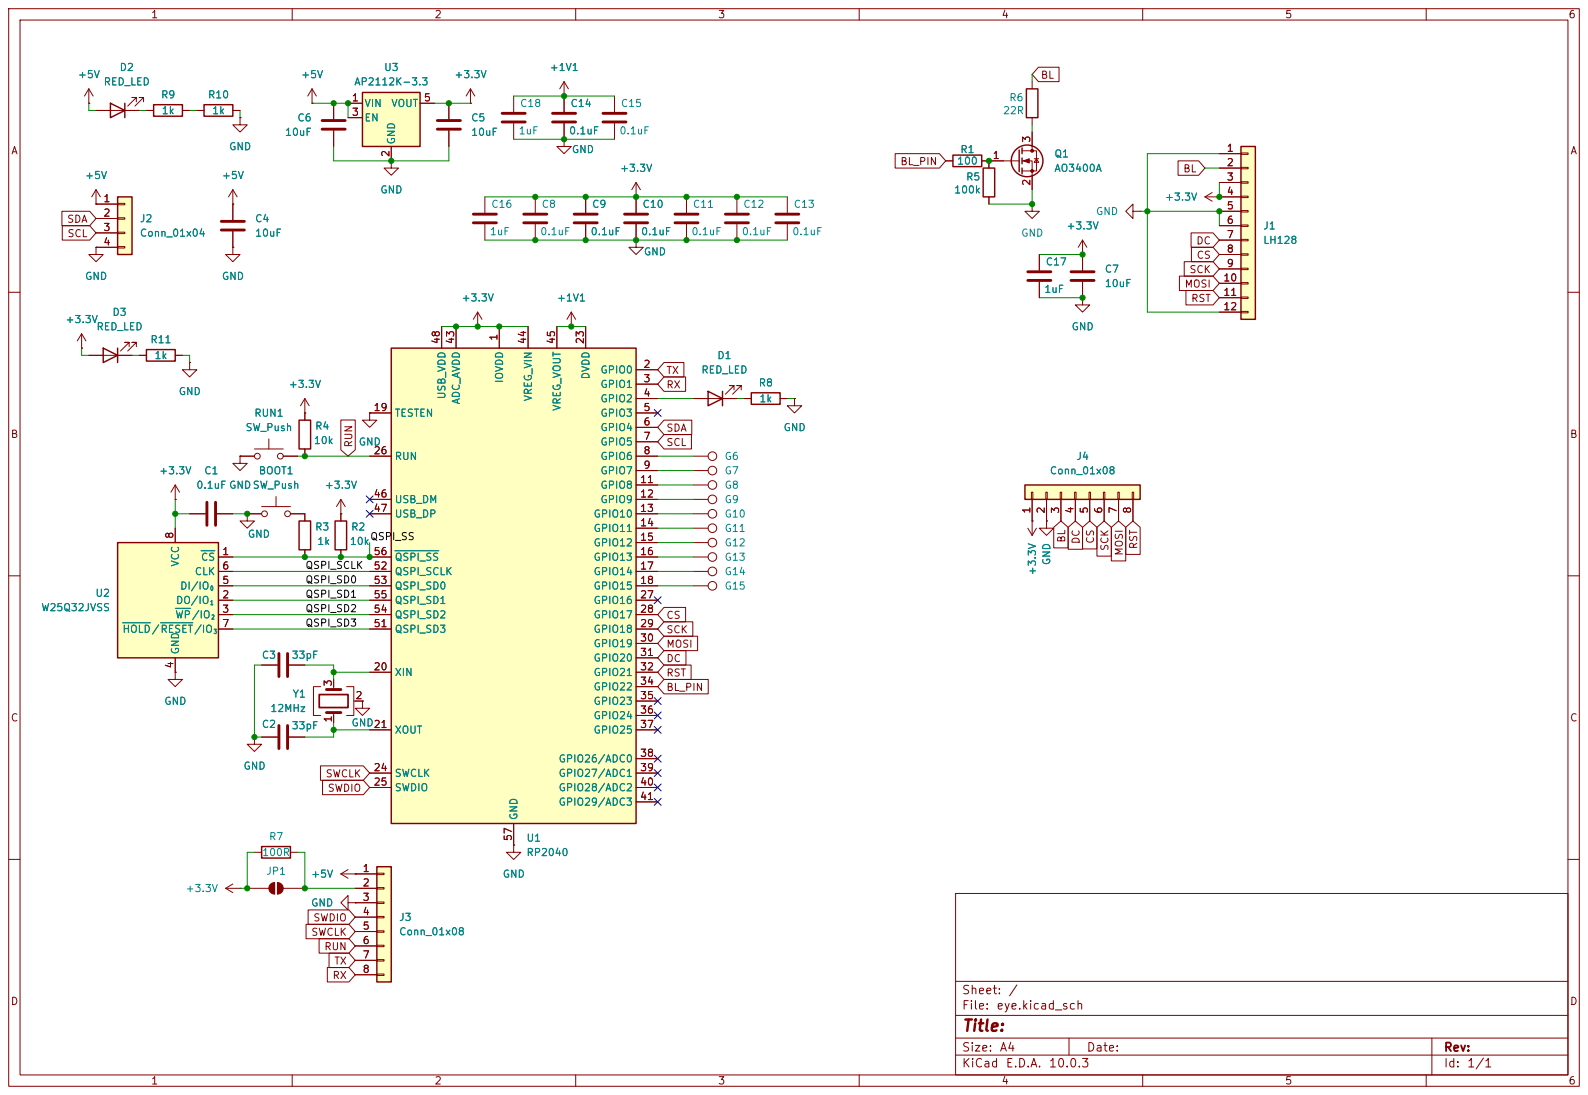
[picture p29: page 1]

Size: A4 | Rev:
KiCad E.D.A. 10.0.3 | Id: 1/1

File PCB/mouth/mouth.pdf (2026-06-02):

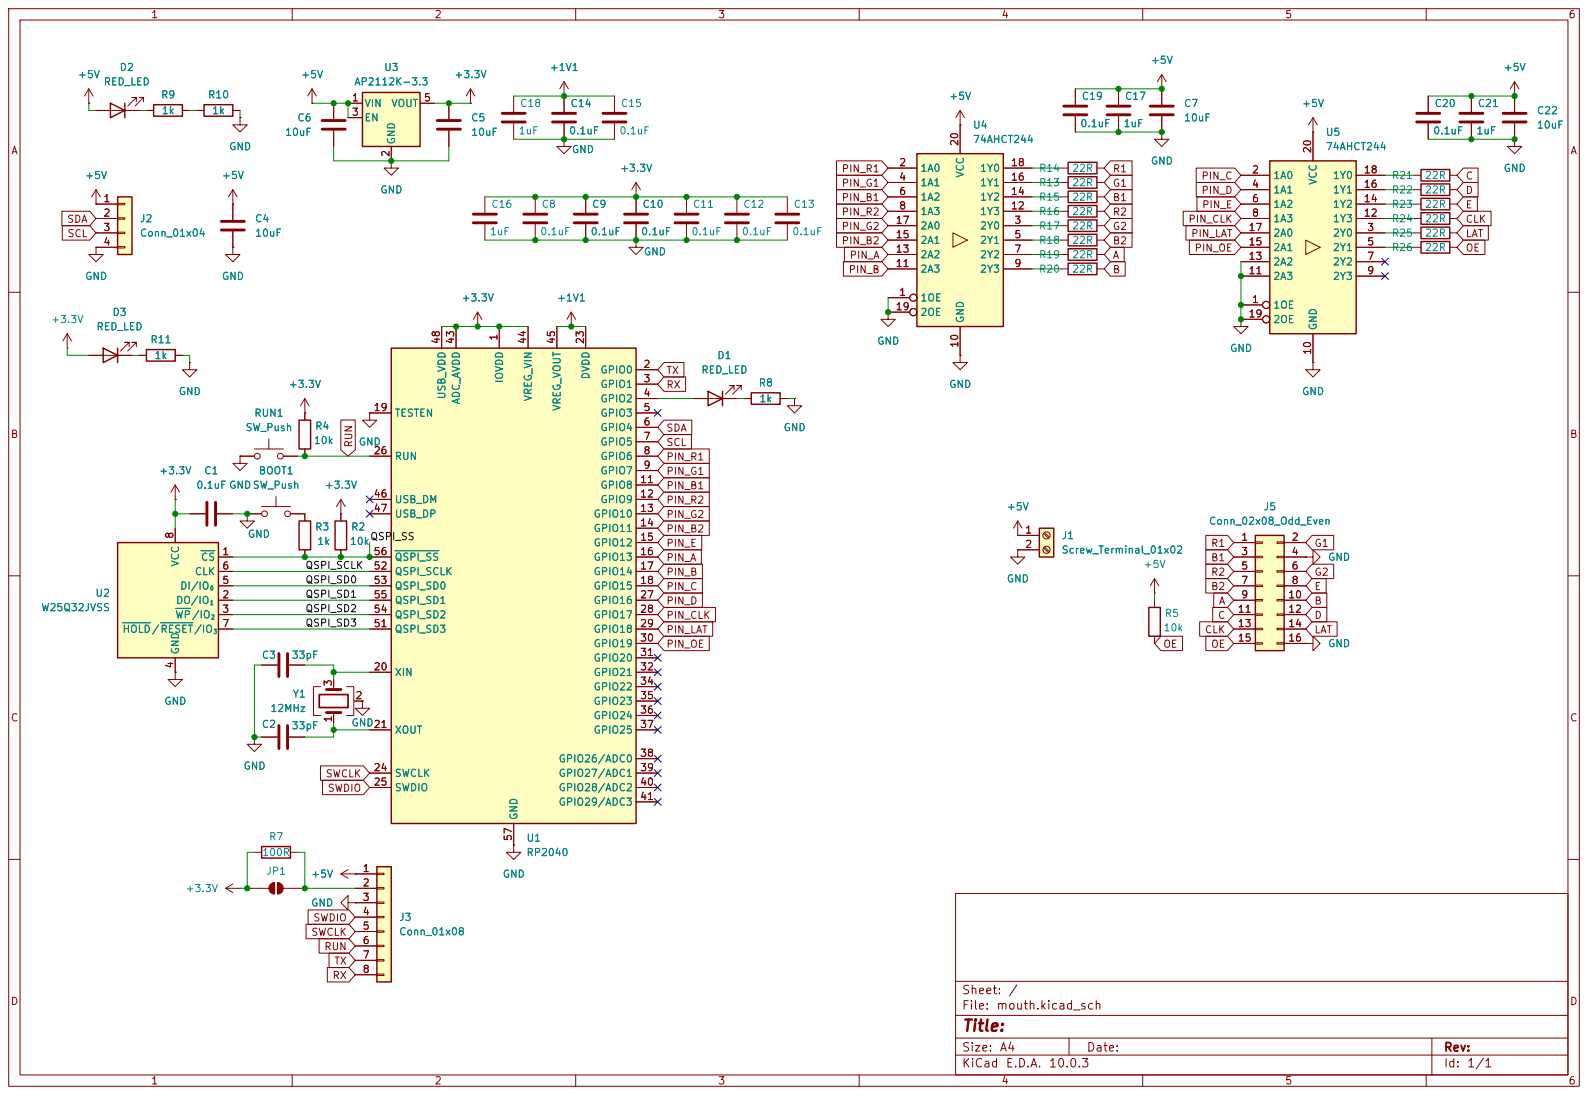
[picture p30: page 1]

4 DI/IO0 5 CLK 6 HOLD/RESET/IO3 7 VCC

Size: A4 | Rev:
KiCad E.D.A. 10.0.3 | Id: 1/1

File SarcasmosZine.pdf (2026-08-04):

# SSSaaarrrcccaaasssmmmOOOSSS

## Sarcastic assistant ! !

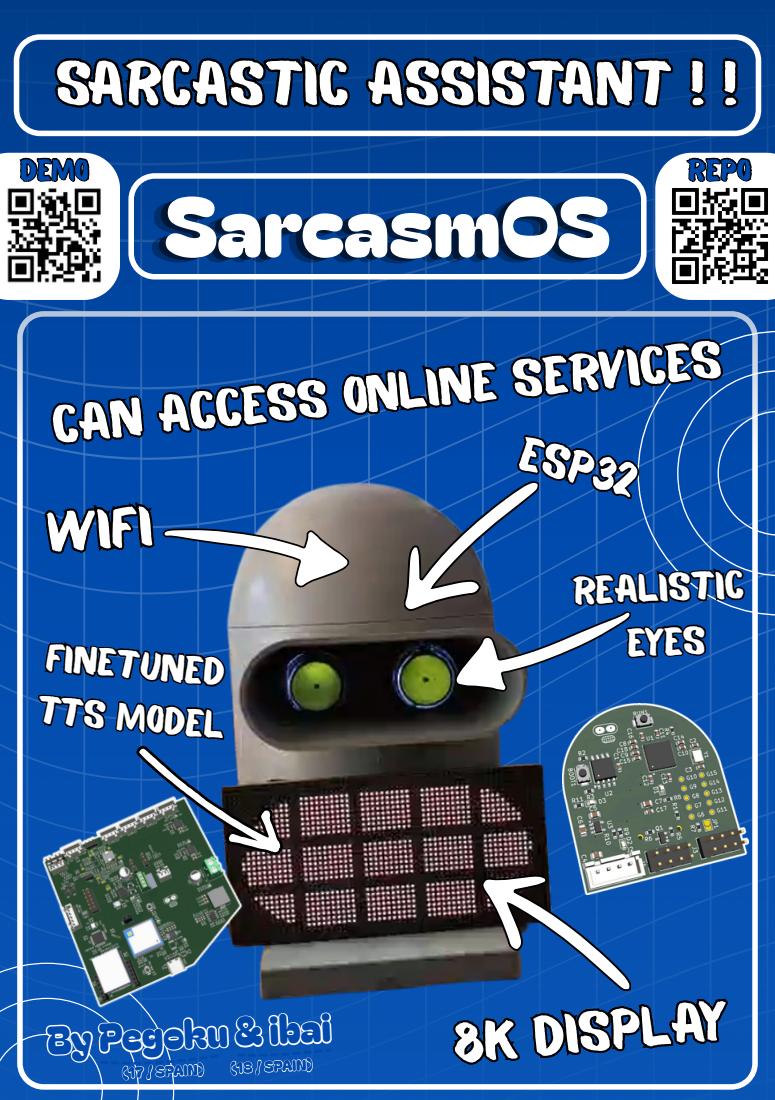
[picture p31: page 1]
Finetuned Finetuned Finetuned TTS model; RReeaalliissttiicc eyes; Realistic eyes; ESP32; WiFi; demo; REPO

Can access Online services

TTS model

8k display 8k display 8k display

BBy Pegoku & ibai By Pegoku & ibai y Pegoku & ibai

(17 / SPAIN) (17 / SPAIN) (17 / SPAIN) (18 / SPAIN) (18 / SPAIN) (18 / SPAIN)

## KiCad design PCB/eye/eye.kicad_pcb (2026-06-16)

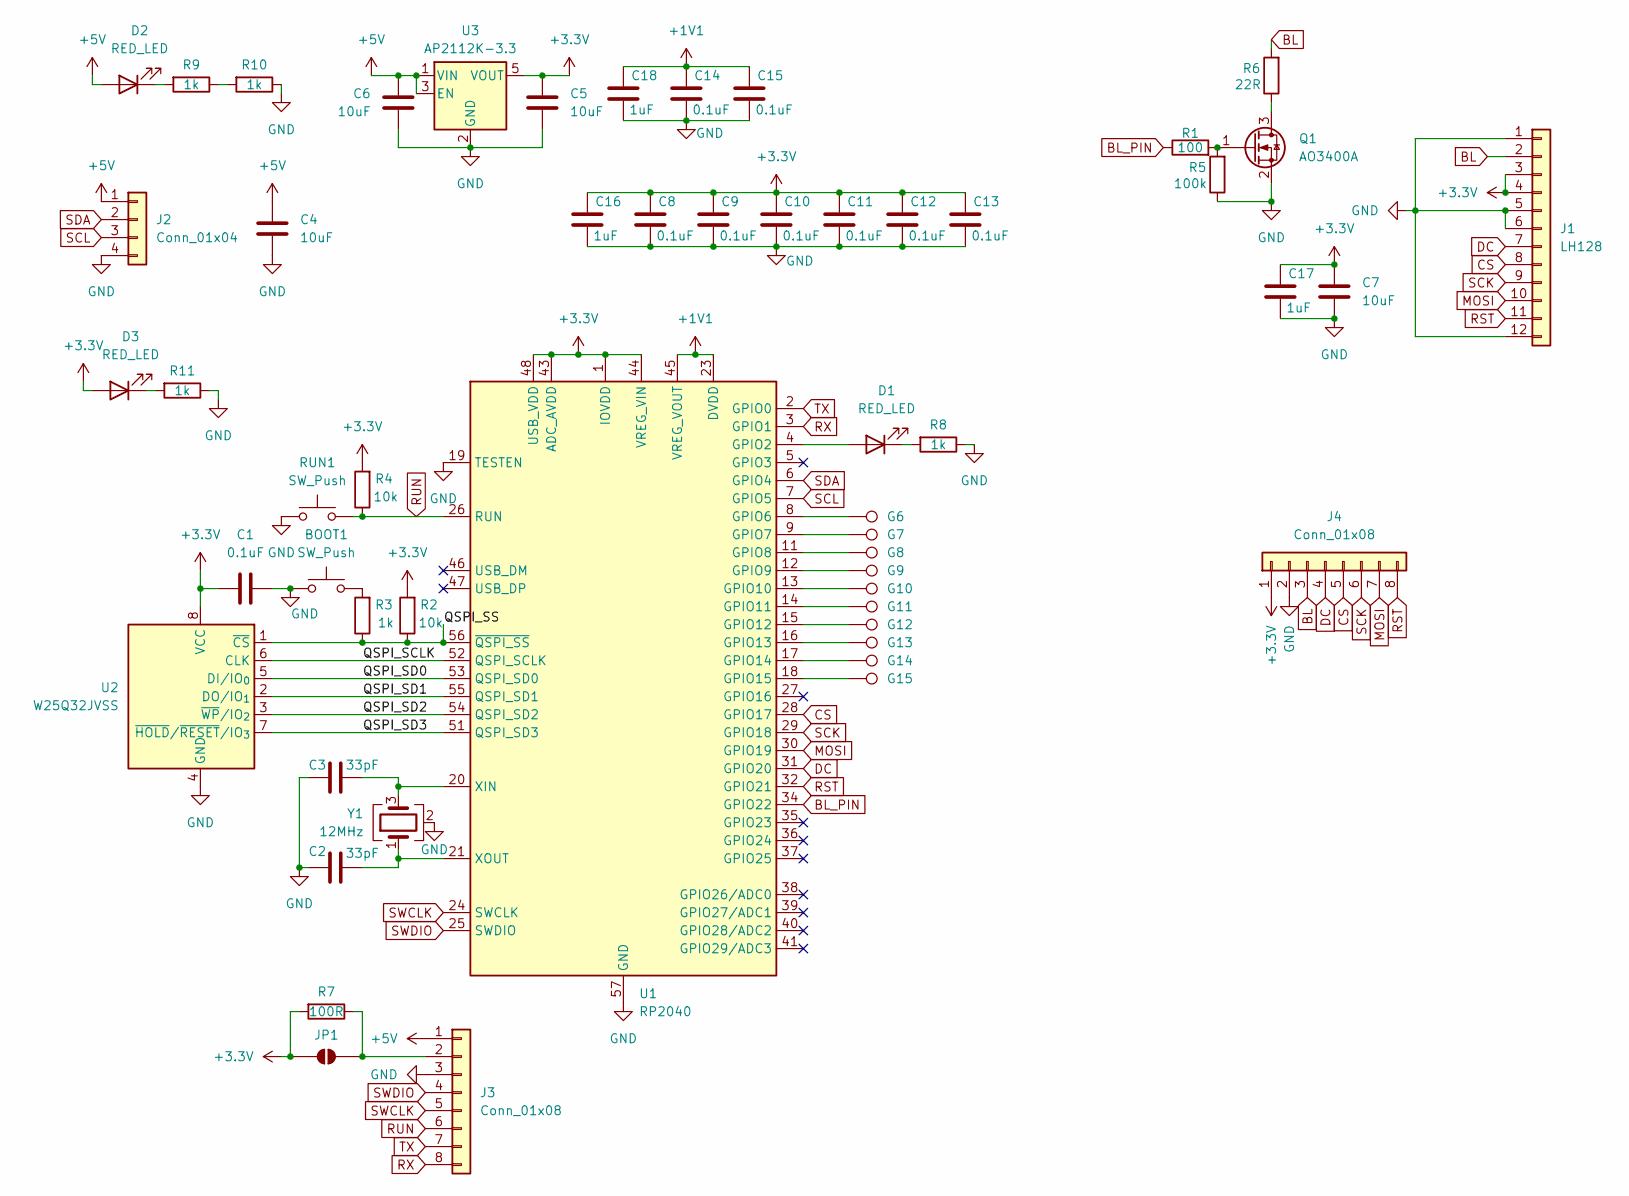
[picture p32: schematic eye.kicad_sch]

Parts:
BOOT1: SW_Push; SW_SPST_TS-1088-xR025; LCSC Part C720477
C1, C8, C9, C10, C11, C12, C13, C14, C15: 0.1uF; C_0603_1608Metric
C2, C3: 33pF; C_0603_1608Metric; LCSC Part C1663
C4, C5, C6, C7: 10uF; C_0805_2012Metric
C16, C17, C18: 1uF; C_0603_1608Metric
D1, D2, D3: RED_LED; LED_0603_1608Metric; LCSC Part C19171390
G6, G7, G8, G9, G10, G11, G12, G13, G14, G15: TestPoint; TestPoint_Pad_D1.0mm
J1: LH128; LH128R
J2: Conn_01x04; JST_XH_B4B-XH-A_1x04_P2.50mm_Vertical; LCSC Part C144395
J3, J4: Conn_01x08; PinHeader_2x04_P2.54mm_Vertical; LCSC Part C5383105
JP1: SolderJumper_2_Open; SolderJumper-2_P1.3mm_Open_TrianglePad1.0x1.5mm
Q1: AO3400A; SOT-23
R1: 100; R_0603_1608Metric
R2, R4: 10k; R_0603_1608Metric
R3, R8, R9, R10, R11: 1k; R_0603_1608Metric
R5: 100k; R_0603_1608Metric
R6: 22R; R_0603_1608Metric
R7: 100R; R_0603_1608Metric
RUN1: SW_Push; SW_SPST_TS-1088-xR025; LCSC Part C720477
U1: RP2040; QFN-56-1EP_7x7mm_P0.4mm_EP3.2x3.2mm; LCSC Part C2040
U2: W25Q32JVSS; SOIC-8_5.3x5.3mm_P1.27mm
U3: AP2112K-3.3; SOT-23-5
Y1: 12MHz; Crystal_SMD_3225-4Pin_3.2x2.5mm; LCSC Part C9002

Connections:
+1V1: C14.2, C15.2, C18.2, U1.23 (DVDD), U1.45 (VREG_VOUT), U1.50 (DVDD)
+3.3V: C1.1, C5.2, C7.2, C8.2, C9.2, C10.2, C11.2, C12.2, C13.2, C16.2, C17.2, D3.2 (A), J1.3, J1.4, J4.1, JP1.1 (A), R2.2, R4.2, R7.2, U1.1 (IOVDD), U1.10 (IOVDD), U1.22 (IOVDD), U1.33 (IOVDD), U1.42 (IOVDD), U1.43 (ADC_AVDD), U1.44 (VREG_VIN), U1.48 (USB_VDD), U1.49 (IOVDD), U2.8 (VCC), U3.5 (VOUT)
+5V: C4.2, C6.2, D2.2 (A), J2.1, J3.1, U3.1 (VIN), U3.3 (EN)
/QSPI_SCLK: U1.52 (QSPI_SCLK), U2.6 (CLK)
/QSPI_SD0: U1.53 (QSPI_SD0), U2.5 (DI/IO_{0})
/QSPI_SD1: U1.55 (QSPI_SD1), U2.2 (DO/IO_{1})
/QSPI_SD2: U1.54 (QSPI_SD2), U2.3 (~WP/IO_{2})
/QSPI_SD3: U1.51 (QSPI_SD3), U2.7 (~HOLD/~RESET/IO_{3})
/QSPI_SS: R2.1, R3.1, U1.56 (~QSPI_SS), U2.1 (~CS)
BL: J1.2, J4.3, R6.2
BL_PIN: R1.1, U1.34 (GPIO22)
CS: J1.8, J4.5, U1.28 (GPIO17)
DC: J1.7, J4.4, U1.31 (GPIO20)
GND: BOOT1.1, C1.2, C2.1, C3.1, C4.1, C5.1, C6.1, C7.1, C8.1, C9.1, C10.1, C11.1, C12.1, C13.1, C14.1, C15.1, C16.1, C17.1, C18.1, J1.1, J1.5, J1.6, J1.12, J2.4, J3.3, J4.2, Q1.2 (S), R5.1, R8.1, R10.1, R11.1, RUN1.1, U1.19 (TESTEN), U1.57 (GND), U2.4 (GND), U3.2 (GND), Y1.2 (G), Y1.4 (G)
MOSI: J1.10, J4.7, U1.30 (GPIO19)
unnamed: BOOT1.2, R3.2
unnamed: D1.2 (A), U1.4 (GPIO2)
unnamed: D1.1 (K), R8.2
unnamed: D2.1 (K), R9.2
unnamed: D3.1 (K), R11.2
unnamed: J3.2, JP1.2 (B), R7.1
unnamed: Q1.3 (D), R6.1
unnamed: Q1.1 (G), R1.2, R5.2
unnamed: R9.1, R10.2
unnamed: G6.1 (1_1), U1.8 (GPIO6)
unnamed: G7.1 (1_1), U1.9 (GPIO7)
unnamed: G8.1 (1_1), U1.11 (GPIO8)
unnamed: G9.1 (1_1), U1.12 (GPIO9)
unnamed: G10.1 (1_1), U1.13 (GPIO10)
unnamed: G11.1 (1_1), U1.14 (GPIO11)
unnamed: G12.1 (1_1), U1.15 (GPIO12)
unnamed: G13.1 (1_1), U1.16 (GPIO13)
unnamed: G14.1 (1_1), U1.17 (GPIO14)
unnamed: G15.1 (1_1), U1.18 (GPIO15)
unnamed: C3.2, U1.20 (XIN), Y1.3
unnamed: C2.2, U1.21 (XOUT), Y1.1
RST: J1.11, J4.8, U1.32 (GPIO21)
RUN: J3.6, R4.1, RUN1.2, U1.26 (RUN)
RX: J3.8, U1.3 (GPIO1)
SCK: J1.9, J4.6, U1.29 (GPIO18)
SCL: J2.3, U1.7 (GPIO5)
SDA: J2.2, U1.6 (GPIO4)
SWCLK: J3.5, U1.24 (SWCLK)
SWDIO: J3.4, U1.25 (SWDIO)
TX: J3.7, U1.2 (GPIO0)

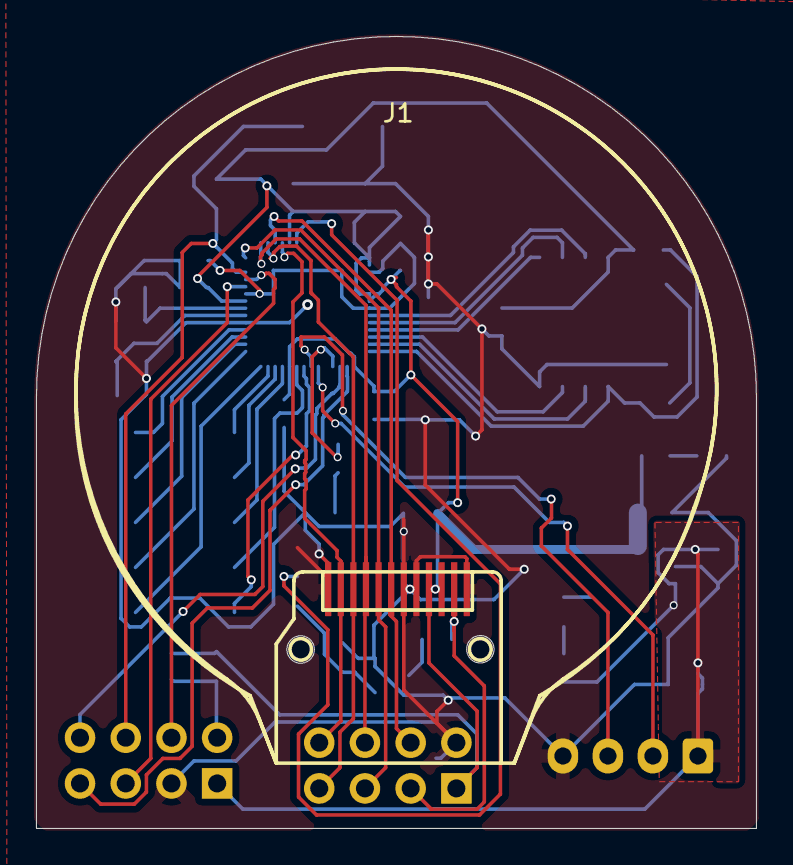
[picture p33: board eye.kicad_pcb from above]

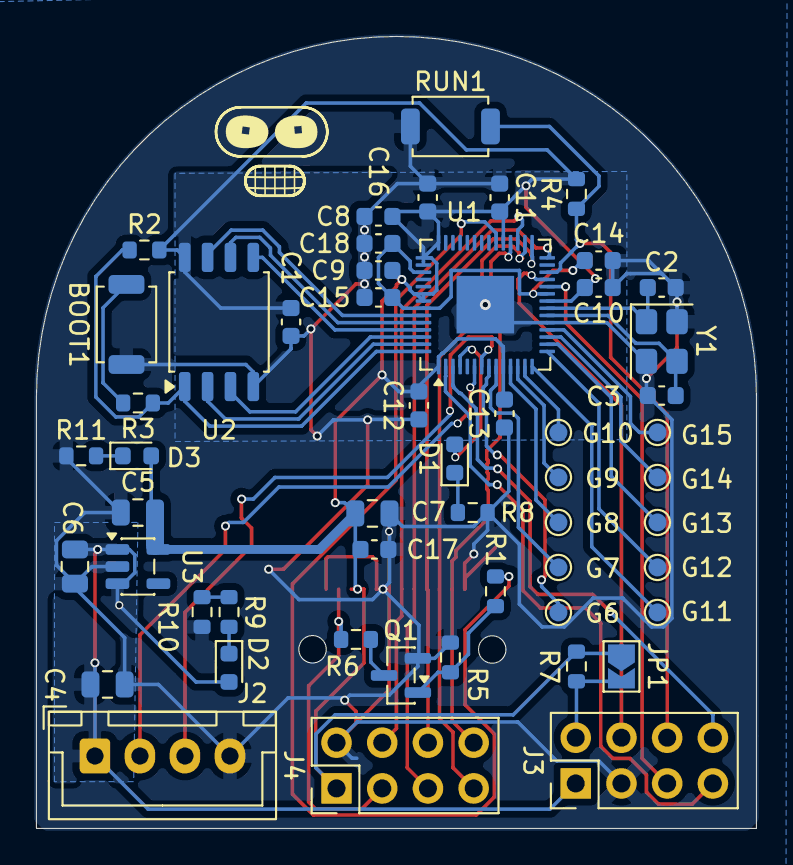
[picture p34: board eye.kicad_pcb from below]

Board: 2 copper layers, 40.0 x 44.0 mm, 54 parts (53 on the bottom side), 45 nets.

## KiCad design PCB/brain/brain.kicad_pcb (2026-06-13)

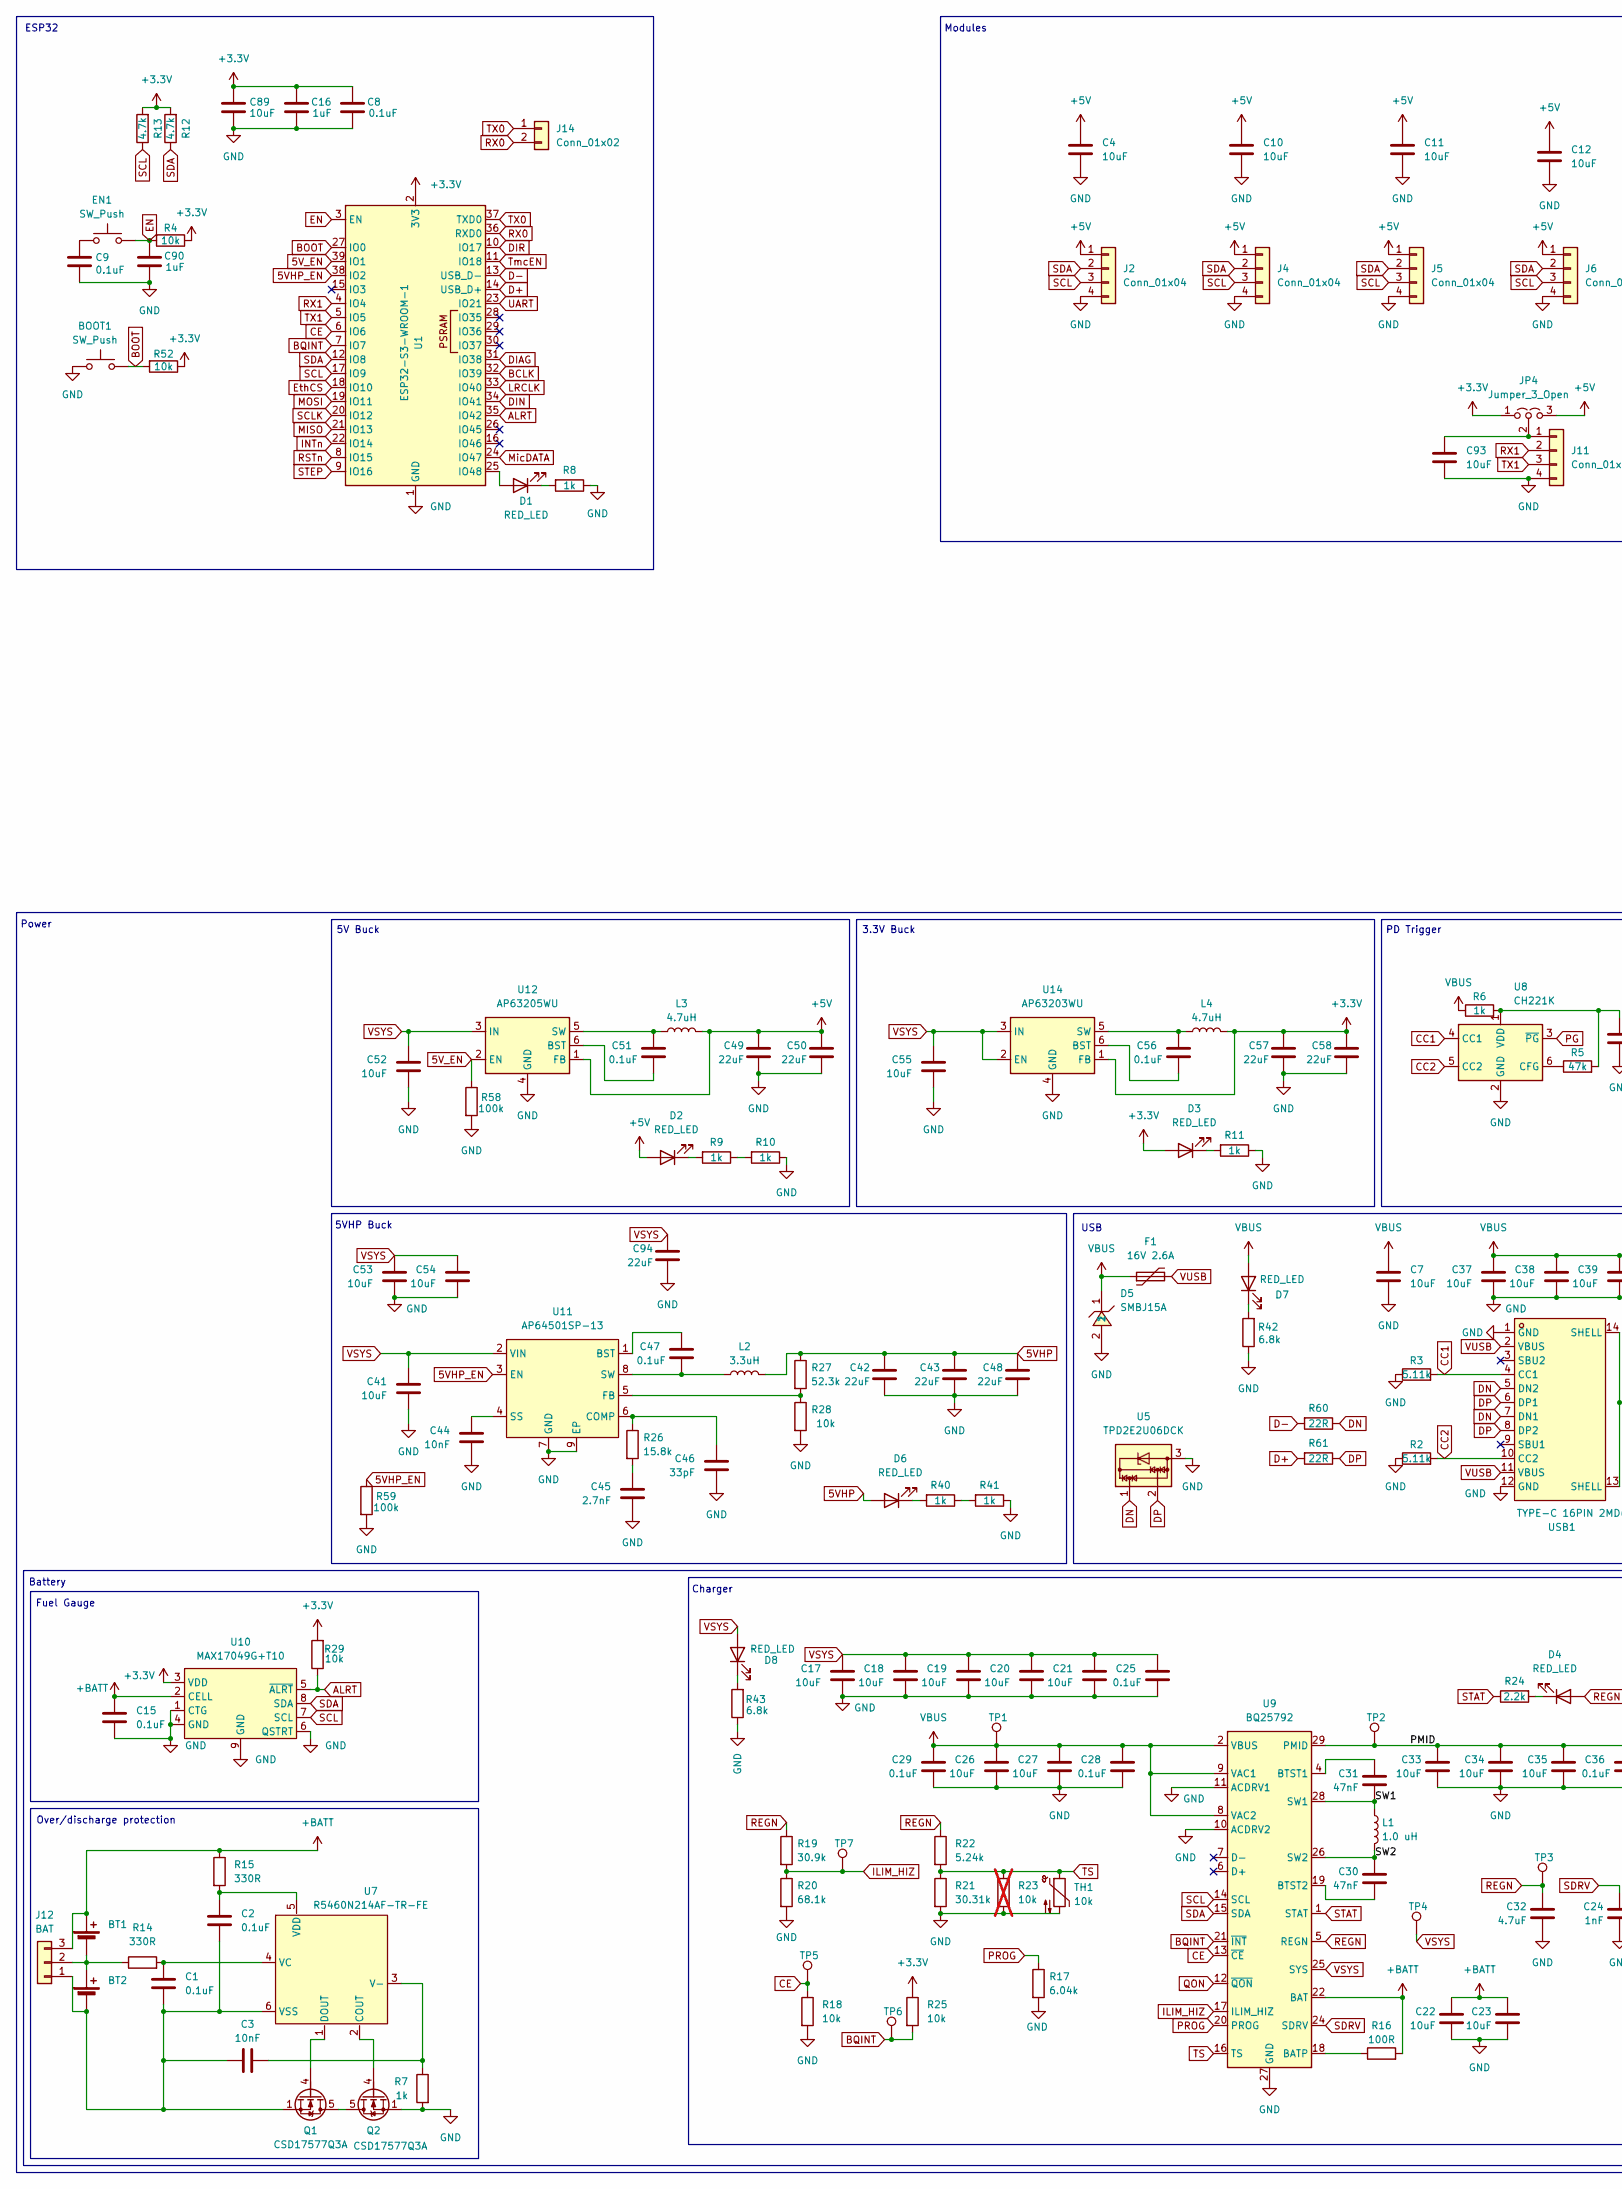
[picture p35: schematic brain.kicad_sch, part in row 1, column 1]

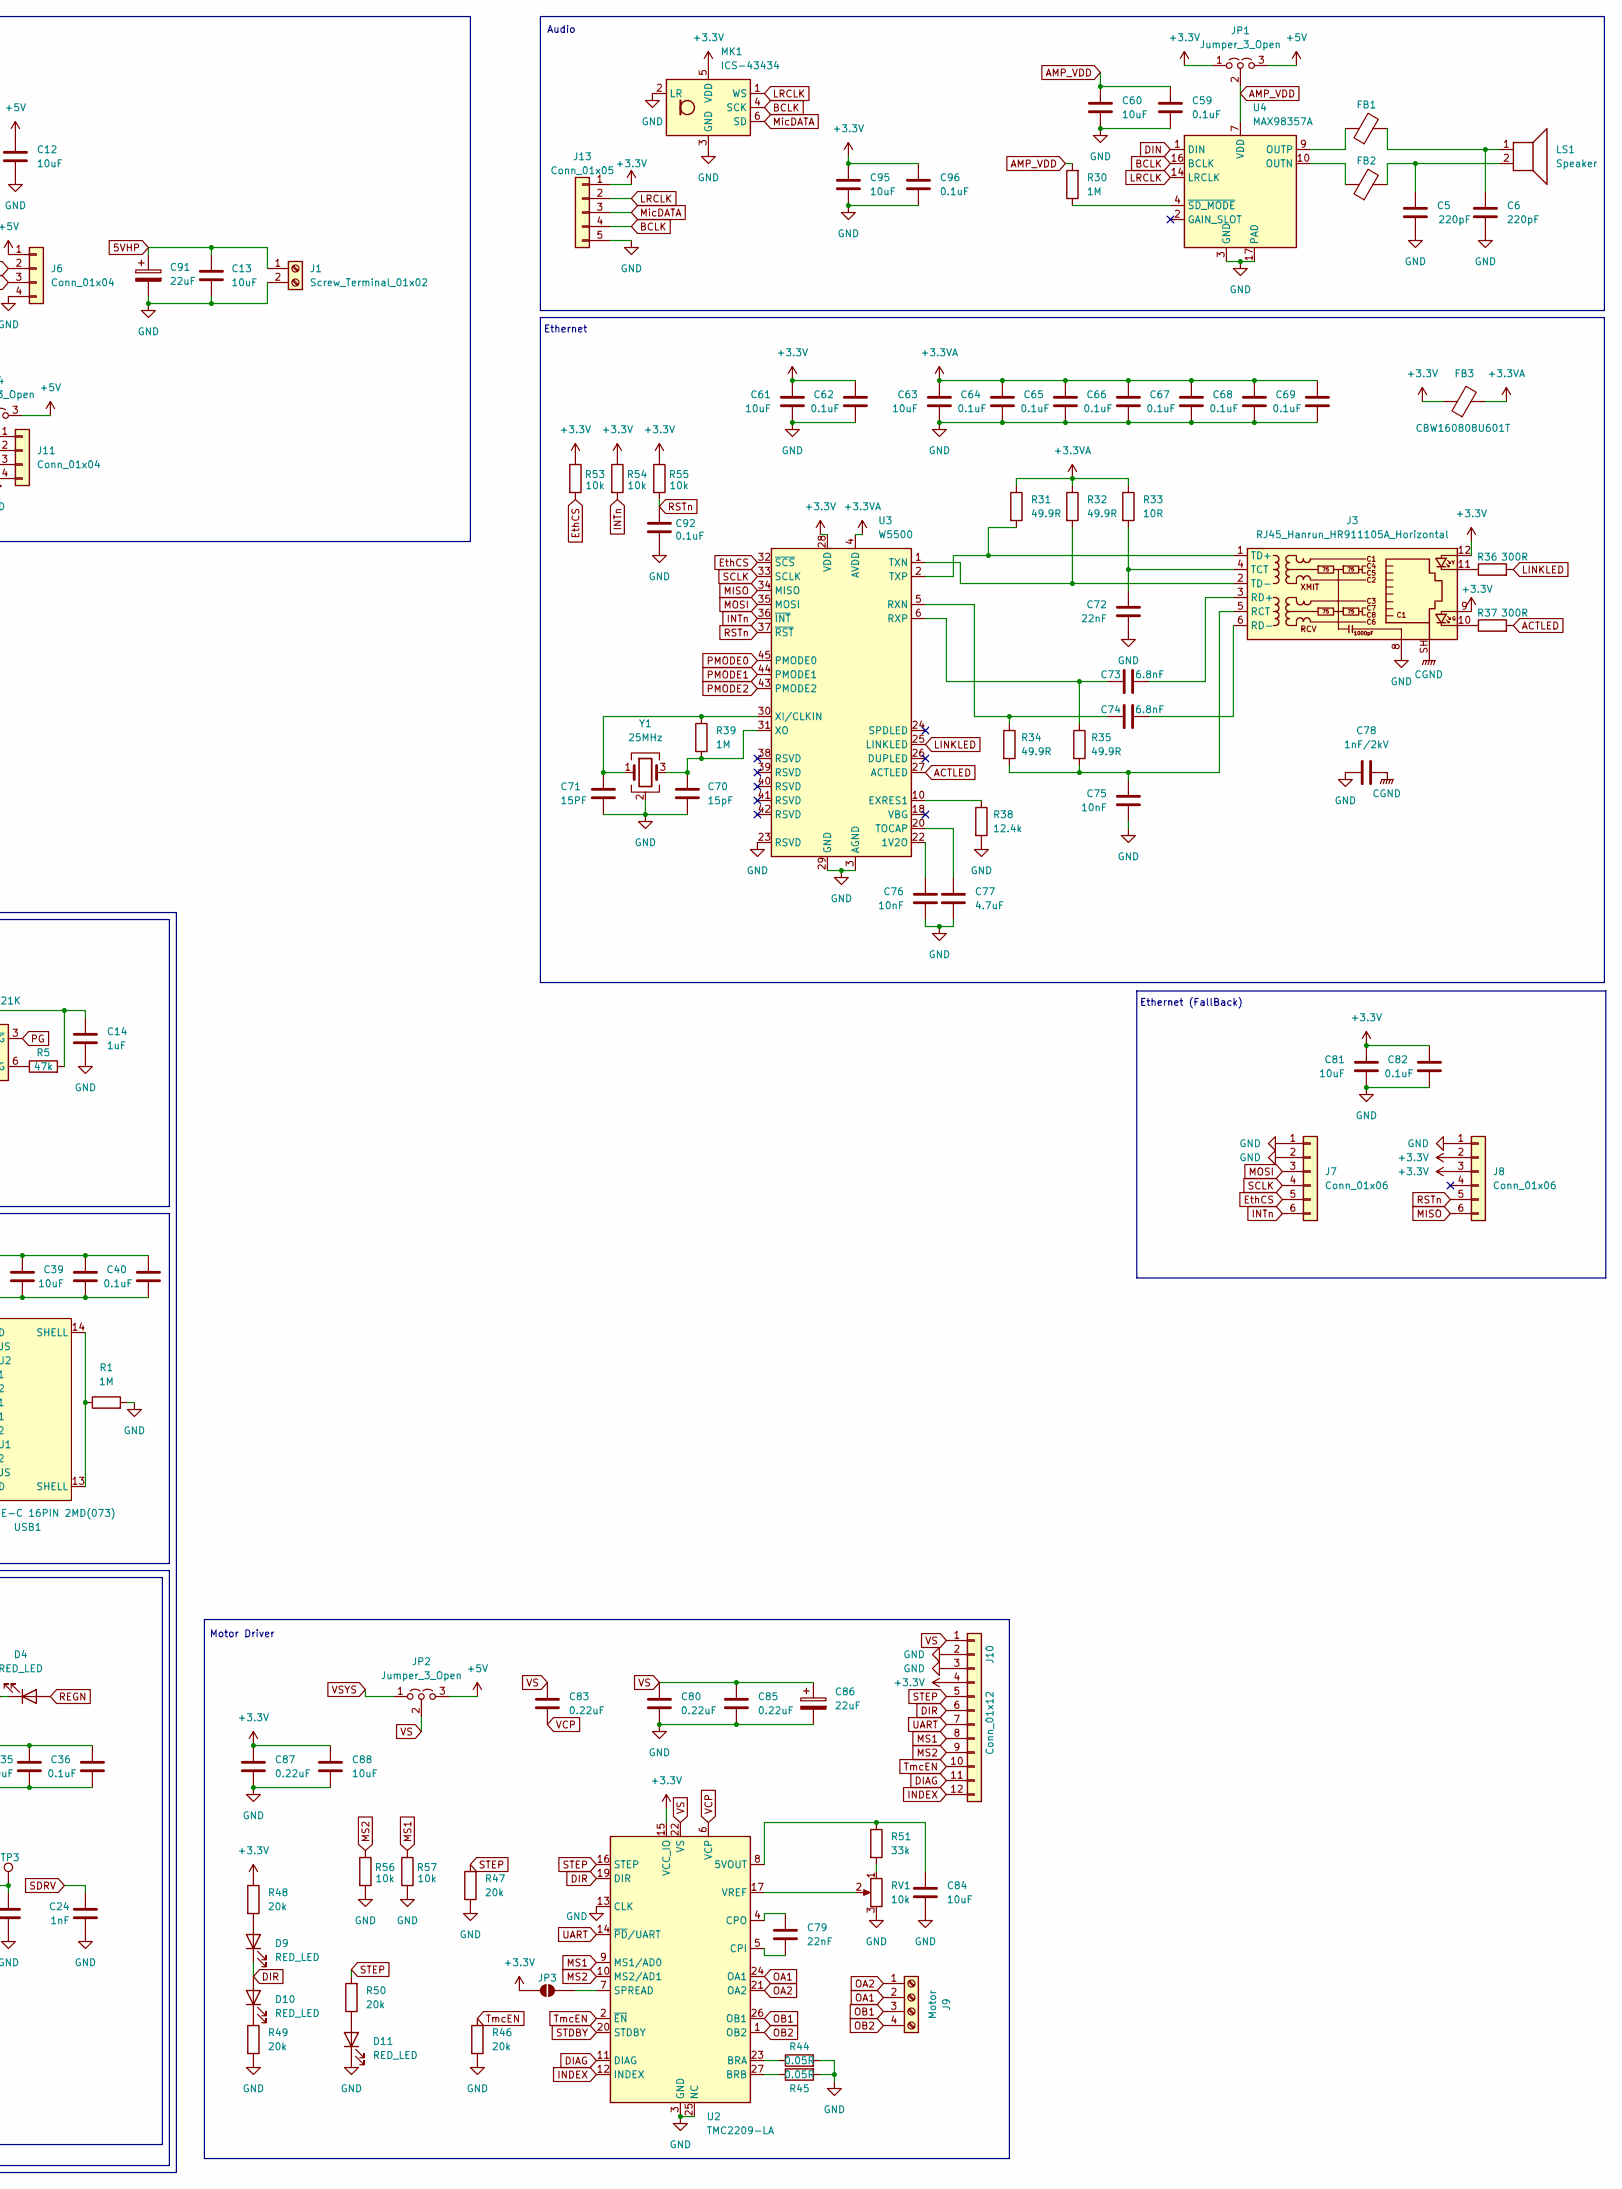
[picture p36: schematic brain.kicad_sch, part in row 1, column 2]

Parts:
BOOT1: SW_Push; SW_SPST_TS-1088-xR025; LCSC Part C720477
BT1, BT2: Battery_Cell; PinHeader_1x02_P2.54mm_Vertical
C1, C2, C15, C29, C47, C51, C56, C92: 0.1uF; C_0603_1608Metric
C3, C44, C75, C76: 10nF; C_0603_1608Metric
C4, C7, C10, C11, C12, C13, C60, C61, C63, C81, C84, C88, C89, C93, C95: 10uF; C_0603_1608Metric
C5, C6: 220pF; C_0603_1608Metric
C8, C25, C28, C36, C40, C59, C62, C64, C65, C66, C67, C68, C69, C96: 0.1uF; C_0402_1005Metric; LCSC Part C77020
C9, C82: 0.1uF; C_0402_1005Metric
C14, C16, C90: 1uF; C_0603_1608Metric
C17, C18, C19, C20, C21, C22, C23, C26, C27, C33, C34, C35, C37, C38, C39, C41, C52, C53, C54, C55: 10uF; C_0603_1608Metric; LCSC Part C194427
C24: 1nF; C_0603_1608Metric
C30, C31: 47nF; C_0603_1608Metric
C32, C77: 4.7uF; C_0603_1608Metric
C42, C94: 22uF; C_0805_2012Metric; LCSC Part C162295
C43, C48, C49, C50, C57, C58: 22uF; C_0805_2012Metric
C45: 2.7nF; C_0603_1608Metric
C46: 33pF; C_0603_1608Metric
C70: 15pF; C_0603_1608Metric; LCSC Part C1644
C71: 15PF; C_0603_1608Metric; LCSC Part C1644
C72, C79: 22nF; C_0603_1608Metric
C73, C74: 6.8nF; C_0603_1608Metric
C78: 1nF/2kV; C_1206_3216Metric; LCSC Part C23631
C80, C83, C85, C87: 0.22uF; C_0603_1608Metric
C86, C91: 22uF; CAP-SMD_BD6.3-L6.6-W6.6-FD; LCSC Part C72505
D1, D2, D3, D4, D6, D7, D8, D9, D10, D11: RED_LED; LED_0603_1608Metric; LCSC Part C19171390
D5: SMBJ15A; SMB_L4.6-W3.6-LS5.3-RD; MPN SMBJ15A; LCSC Part C83846
EN1: SW_Push; SW_SPST_TS-1088-xR025; LCSC Part C720477
F1: 16V 2.6A; Fuse_1812_4532Metric_Pad1.30x3.40mm_HandSolder; LCSC Part C438899
FB1, FB2: FerriteBead; L_0603_1608Metric; LCSC Part C88989
FB3: CBW160808U601T; L_0603_1608Metric; LCSC Part C139183
J1: Screw_Terminal_01x02; TerminalBlock_Phoenix_PT-1,5-2-5.0-H_1x02_P5.00mm_Horizontal; LCSC Part C474881
J2, J4, J5, J6, J11: Conn_01x04; JST_XH_B4B-XH-A_1x04_P2.50mm_Vertical; LCSC Part C144395
J3: RJ45_Hanrun_HR911105A_Horizontal; LCSC Part C12074
J7, J8: Conn_01x06; PinSocket_1x06_P2.54mm_Vertical
J9: Motor; CONN-TH_4P-P2.54_MX128-2.54-GN01-04P-CU-Y-A; LCSC Part C5188444
J10: Conn_01x12; PinHeader_2x06_P2.54mm_Vertical
J12: BAT; JST_XH_B3B-XH-A_1x03_P2.50mm_Vertical
J13: Conn_01x05; JST_XH_B5B-XH-A_1x05_P2.50mm_Vertical
J14: Conn_01x02; PinSocket_1x02_P2.54mm_Vertical
JP1, JP2, JP4: Jumper_3_Open; PinHeader_1x03_P2.54mm_Vertical
JP3: SolderJumper_2_Open; SolderJumper-2_P1.3mm_Open_TrianglePad1.0x1.5mm
L1: 1.0 uH; IND-SMD_L7.1-W6.5-P5.60; LCSC Part C87572
L2: 3.3uH; IND-SMD_L11.5-W10.0_SMMS1040; LCSC Part C149592
L3, L4: 4.7uH; IND-SMD_L5.0-W5.0; LCSC Part C354606
LS1: Speaker; JST_XH_B2B-XH-AM_1x02_P2.50mm_Vertical
MK1: ICS-43434; InvenSense_ICS-43434-6_3.5x2.65mm
Q1, Q2: CSD17577Q3A; VSON-8_3.3x3.3mm_P0.65mm_NexFET
R1, R30, R39: 1M; R_0603_1608Metric
R2, R3: 5.11k; R_0603_1608Metric
R4, R18, R25, R28, R29, R52, R53, R54, R55, R56, R57: 10k; R_0603_1608Metric
R5: 47k; R_0603_1608Metric
R6, R7, R8, R9, R10, R11, R40, R41: 1k; R_0603_1608Metric
R12, R13: 4.7k; R_0603_1608Metric
R14, R15: 330R; R_0603_1608Metric
R16: 100R; R_0603_1608Metric
R17: 6.04k; R_0603_1608Metric
R19: 30.9k; R_0603_1608Metric
R20: 68.1k; R_0603_1608Metric
R21: 30.31k; R_0603_1608Metric
R22: 5.24k; R_0603_1608Metric
R23: 10k; R_0603_1608Metric; not fitted
R24: 2.2k; R_0603_1608Metric
R26: 15.8k; R_0603_1608Metric
R27: 52.3k; R_0603_1608Metric
R31, R32, R34, R35: 49.9R; R_0603_1608Metric
R33: 10R; R_0603_1608Metric
R36, R37: 300R; R_0603_1608Metric
R38: 12.4k; R_0603_1608Metric
R42, R43: 6.8k; R_0603_1608Metric
R44, R45: 0.05R; R_1206_3216Metric
R46, R47, R48, R49, R50: 20k; R_0603_1608Metric
R51: 33k; R_0603_1608Metric
R58, R59: 100k; R_0603_1608Metric
R60, R61: 22R; C_0402_1005Metric
RV1: 10k; RES-ADJ-SMD_3P-L3.8-W3.7_VGF39NCHXT; LCSC Part C22461454
TH1: 10k; PinHeader_1x02_P2.54mm_Vertical
TP1, TP2, TP3, TP4, TP5, TP6, TP7: TestPoint; TestPoint_Pad_D1.5mm
U1: ESP32-S3-WROOM-1; ESP32-S3-WROOM-1U; LCSC Part C2913199
U2: TMC2209-LA; VQFN-28-1EP_5x5mm_P0.5mm_EP3.7x3.7mm_ThermalVias
U3: W5500; LQFP-48_7x7mm_P0.5mm; LCSC Part C32843
U4: MAX98357A; TQFN-16-1EP_3x3mm_P0.5mm_EP1.23x1.23mm
U5: TPD2E2U06DCK; SOT-323_SC-70
U7: R5460N214AF-TR-FE; SOT-23-6_L2.9-W1.6-P0.95-LS2.8-BL; MPN R5460N214AF-TR-FE; LCSC Part C259719
U8: CH221K; SOT-23-6
U9: BQ25792; Texas_RQM0029A_VQFN-29_4x4mm_P0.4mm
U10: MAX17049G+T10; WSON-8_L2.0-W2.0-P0.50-BL-EP0.9; MPN MAX17049G+T10; LCSC Part C18185545
U11: AP64501SP-13; SOIC-8-1EP_3.9x4.9mm_P1.27mm_EP2.29x3mm_ThermalVias; MPN AP64501SP-13; LCSC Part C2071517
U12: AP63205WU; TSOT-23-6
U14: AP63203WU; TSOT-23-6
USB1: TYPE-C 16PIN 2MD(073); USB-C-SMD_TYPE-C-6PIN-2MD-073; LCSC Part C2765186
Y1: 25MHz; Crystal_SMD_3225-4Pin_3.2x2.5mm; LCSC Part C13740

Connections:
5VHP: C13.2, C42.2, C43.2, C48.2, C91.1, D6.2 (A), J1.1, L2.2, R27.1
5VHP_EN: R59.1, U1.38 (IO2), U11.3 (EN)
5V_EN: R58.1, U1.39 (IO1), U12.2 (EN)
+3.3V: C8.2, C16.2, C57.2, C58.2, C61.2, C62.2, C81.2, C82.2, C87.1, C88.2, C89.2, C95.1, C96.1, D3.2 (A), FB3.1, J3.9, J3.12, J8.2, J8.3, J10.4, J13.1, JP1.1 (A), JP3.1 (A), JP4.1 (A), L4.2, MK1.5 (VDD), R4.1, R12.2, R13.2, R25.1, R29.2, R48.1, R52.1, R53.1, R54.1, R55.1, U1.2 (3V3), U2.15 (VCC_IO), U3.28 (VDD), U10.3 (VDD), U14.1 (FB)
+3.3VA: C63.2, C64.2, C65.2, C66.2, C67.2, C68.2, C69.2, FB3.2, R31.1, R32.1, R33.1, U3.4 (AVDD), U3.8 (AVDD), U3.11 (AVDD), U3.15 (AVDD), U3.17 (AVDD), U3.21 (AVDD)
+5V: C4.2, C10.2, C11.2, C12.2, C49.2, C50.2, D2.2 (A), J2.1, J4.1, J5.1, J6.1, JP1.3 (B), JP2.3 (B), JP4.3 (B), L3.2, U12.1 (FB)
+BATT: BT1.1 (+), C15.1, C22.2, C23.2, J12.3, R15.1, R16.2, U9.22 (BAT), U9.23 (BAT), U10.2 (CELL)
/PMID: C33.2, C34.2, C35.2, C36.2, TP2.1 (1_1), U9.29 (PMID)
/SW1: C31.1, L1.1, U9.28 (SW1)
/SW2: C30.2, L1.2, U9.26 (SW2)
ACTLED: R37.2, U3.27 (ACTLED)
ALRT: R29.1, U1.35 (IO42), U10.5 (~ALRT)
AMP_VDD: C59.1, C60.1, JP1.2 (C), R30.2, U4.7 (VDD), U4.8 (VDD)
BCLK: J13.4, MK1.4 (SCK), U1.32 (IO39), U4.16 (BCLK)
BOOT: BOOT1.2, R52.2, U1.27 (IO0)
BQINT: R25.2, TP6.1 (1_1), U1.7 (IO7), U9.21 (~INT)
CC1: R3.2, U8.4 (CC1), USB1.4 (CC1)
CC2: R2.2, U8.5 (CC2), USB1.10 (CC2)
CE: R18.1, TP5.1 (1_1), U1.6 (IO6), U9.13 (~CE)
CGND: C78.2, J3.SH
D+: R61.2, U1.14 (USB_D+)
D-: R60.2, U1.13 (USB_D-)
DIAG: J10.11, U1.31 (IO38), U2.11 (DIAG)
DIN: U1.34 (IO41), U4.1 (DIN)
DIR: D9.1 (K), D10.2 (A), J10.6, U1.10 (IO17), U2.19 (DIR)
DN: R60.1, U5.1, USB1.5 (DN2), USB1.7 (DN1)
DP: R61.1, U5.2, USB1.6 (DP1), USB1.8 (DP2)
EN: C90.2, EN1.2, R4.2, U1.3 (EN)
EthCS: J7.5, R53.2, U1.18 (IO10), U3.32 (~SCS)
GND: BOOT1.1, C4.1, C5.2, C6.2, C7.1, C8.1, C9.1, C10.1, C11.1, C12.1, C13.1, C14.1, C15.2, C16.1, C17.1, C18.1, C19.1, C20.1, C21.1, C22.1, C23.1, C24.1, C25.1, C26.1, C27.1, C28.1, C29.1, C32.1, C33.1, C34.1, C35.1, C36.1, C37.1, C38.1, C39.1, C40.1, C41.1, C42.1, C43.1, C44.1, C45.1, C46.1, C48.1, C49.1, C50.1, C52.1, C53.1, C54.1, C55.1, C57.1, C58.1, C59.2, C60.2, C61.1, C62.1, C63.1, C64.1, C65.1, C66.1, C67.1, C68.1, C69.1, C70.2, C71.2, C72.1, C75.1, C76.1, C77.1, C78.1, C80.2, C81.1, C82.1, C84.1, C85.2, C86.2, C87.2, C88.1, C89.1, C90.1, C91.2, C92.1, C93.1, C94.1, C95.2, C96.2, D5.2, D11.1 (K), J1.2, J2.4, J3.8, J4.4, J5.4, J6.4, J7.1, J7.2, J8.1, J10.2, J10.3, J11.4, J13.5, MK1.2 (LR), MK1.3 (GND), Q2.1 (S), Q2.2 (S), Q2.3 (S), R1.2, R2.1, R3.1, R7.2, R8.1, R10.1, R11.1, R17.2, R18.2, R20.2, R21.2, R23.2, R28.2, R38.2, R41.1, R42.1, R43.1, R44.2, R45.2, R46.2, R47.1, R49.2, R56.2, R57.2, R58.2, R59.2, RV1.3, TH1.2, U1.1 (GND), U1.40 (GND), U1.41 (GND), U2.3 (GND), U2.13 (CLK), U2.18 (GND), U2.25 (NC), U2.29 (GND), U3.3 (AGND), U3.9 (AGND), U3.14 (AGND), U3.16 (AGND), U3.19 (AGND), U3.23 (RSVD), U3.29 (GND), U3.48 (AGND), U4.3 (GND), U4.11 (GND), U4.15 (GND), U4.17 (PAD), U5.3, U8.2 (GND), U9.10 (ACDRV2), U9.11 (ACDRV1), U9.27 (GND), U10.1 (CTG), U10.4 (GND), U10.6 (QSTRT), U10.9 (GND), U11.7 (GND), U11.9 (EP), U12.4 (GND), U14.4 (GND), USB1.1 (GND), USB1.12 (GND), Y1.2 (G), Y1.4 (G)
ILIM_HIZ: R19.2, R20.1, TP7.1 (1_1), U9.17 (ILIM_HIZ)
INDEX: J10.12, U2.12 (INDEX)
INTn: J7.6, R54.2, U1.22 (IO14), U3.36 (~INT)
LINKLED: R36.2, U3.25 (LINKLED)
LRCLK: J13.2, MK1.1 (WS), U1.33 (IO40), U4.14 (LRCLK)
MISO: J8.6, U1.21 (IO13), U3.34 (MISO)
MOSI: J7.3, U1.19 (IO11), U3.35 (MOSI)
MS1: J10.8, R57.1, U2.9 (MS1/AD0)
MS2: J10.9, R56.1, U2.10 (MS2/AD1)
MicDATA: J13.3, MK1.6 (SD), U1.24 (IO47)
unnamed: BT1.2 (-), BT2.1 (+), J12.2, R14.1
unnamed: BT2.2 (-), C1.2, C2.2, C3.1, J12.1, Q1.1 (S), Q1.2 (S), Q1.3 (S), U7.6 (VSS)
unnamed: C5.1, FB2.2, LS1.2
unnamed: C6.1, FB1.2, LS1.1
unnamed: C9.2, EN1.1
unnamed: C45.2, R26.2
unnamed: D1.2 (A), U1.25 (IO48)
unnamed: D1.1 (K), R8.2
unnamed: D2.1 (K), R9.2
unnamed: D3.1 (K), R11.2
unnamed: D4.1 (K), R24.2
unnamed: D6.1 (K), R40.2
unnamed: D7.1 (K), R42.2
unnamed: D8.1 (K), R43.2
unnamed: D9.2 (A), R48.2
unnamed: D10.1 (K), R49.1
unnamed: D11.2 (A), R50.1
unnamed: J3.10, R37.1
unnamed: J3.11, R36.1
unnamed: C75.2, J3.5 (RCT), R34.2, R35.2
unnamed: C73.1, J3.3 (RD+)
unnamed: C74.1, J3.6 (RD-)
unnamed: C72.2, J3.4 (TCT), R33.2
unnamed: J3.1 (TD+), R31.2, U3.2 (TXP)
unnamed: J3.2 (TD-), R32.2, U3.1 (TXN)
unnamed: C93.2, J11.1, JP4.2 (C)
unnamed: JP3.2 (B), U2.7 (SPREAD)
unnamed: Q1.5 (D), Q2.5 (D)
unnamed: Q1.4 (G), U7.1 (DOUT)
unnamed: Q2.4 (G), U7.2 (COUT)
unnamed: R1.1, USB1.13 (SHELL), USB1.14 (SHELL)
unnamed: R9.1, R10.2
unnamed: R40.1, R41.2
unnamed: R51.2, RV1.1
unnamed: C84.2, R51.1, U2.8 (5VOUT)
unnamed: R44.1, U2.23 (BRA)
unnamed: R45.1, U2.27 (BRB)
unnamed: C79.2, U2.5 (CPI)
unnamed: C79.1, U2.4 (CPO)
unnamed: RV1.2, U2.17 (VREF)
unnamed: C76.2, U3.22 (1V2O)
unnamed: R38.1, U3.10 (EXRES1)
unnamed: C74.2, R34.1, U3.5 (RXN)
unnamed: C73.2, R35.1, U3.6 (RXP)
unnamed: C77.2, U3.20 (TOCAP)
unnamed: C71.1, R39.1, U3.30 (XI/CLKIN), Y1.1
unnamed: C70.1, R39.2, U3.31 (XO), Y1.3
unnamed: FB2.1, U4.10 (OUTN)
unnamed: FB1.1, U4.9 (OUTP)
unnamed: R30.1, U4.4 (~SD_MODE)
unnamed: C3.2, R7.1, U7.3 (V-)
unnamed: C1.1, R14.2, U7.4 (VC)
unnamed: C2.1, R15.2, U7.5 (VDD)
unnamed: R5.1, U8.6 (CFG)
unnamed: C14.2, R5.2, R6.2, U8.1 (VDD)
unnamed: R16.1, U9.18 (BATP)
unnamed: C31.2, U9.4 (BTST1)
unnamed: C30.1, U9.19 (BTST2)
unnamed: C47.2, U11.1 (BST)
unnamed: C46.2, R26.1, U11.6 (COMP)
unnamed: R27.2, R28.1, U11.5 (FB)
unnamed: C44.2, U11.4 (SS)
unnamed: C47.1, L2.1, U11.8 (SW)
unnamed: C51.1, U12.6 (BST)
unnamed: C51.2, L3.1, U12.5 (SW)
unnamed: C56.1, U14.6 (BST)
unnamed: C56.2, L4.1, U14.5 (SW)
OA1: J9.2, U2.24 (OA1)
OA2: J9.1, U2.21 (OA2)
OB1: J9.3, U2.26 (OB1)
OB2: J9.4, U2.1 (OB2)
PG: U8.3 (~PG)
PMODE0: U3.45 (PMODE0)
PMODE1: U3.44 (PMODE1)
PMODE2: U3.43 (PMODE2)
PROG: R17.1, U9.20 (PROG)
QON: U9.12 (~QON)
REGN: C32.2, D4.2 (A), R19.1, R22.1, TP3.1 (1_1), U9.5 (REGN)
RSTn: C92.2, J8.5, R55.2, U1.8 (IO15), U3.37 (~RST)
RX0: J14.2, U1.36 (RXD0)
RX1: J11.2, U1.4 (IO4)
SCL: J2.3, J4.3, J5.3, J6.3, R13.1, U1.17 (IO9), U9.14 (SCL), U10.7 (SCL)
SCLK: J7.4, U1.20 (IO12), U3.33 (SCLK)
SDA: J2.2, J4.2, J5.2, J6.2, R12.1, U1.12 (IO8), U9.15 (SDA), U10.8 (SDA)
SDRV: C24.2, U9.24 (SDRV)
STAT: R24.1, U9.1 (STAT)
STDBY: U2.20 (STDBY)
STEP: J10.5, R47.2, R50.2, U1.9 (IO16), U2.16 (STEP)
TS: R21.1, R22.2, R23.1, TH1.1, U9.16 (TS)
TX0: J14.1, U1.37 (TXD0)
TX1: J11.3, U1.5 (IO5)
TmcEN: J10.10, R46.1, U1.11 (IO18), U2.2 (~EN)
UART: J10.7, U1.23 (IO21), U2.14 (~PD/UART)
VBUS: C7.2, C26.2, C27.2, C28.2, C29.2, C37.2, C38.2, C39.2, C40.2, D5.1, D7.2 (A), F1.1, R6.1, TP1.1 (1_1), U9.2 (VBUS), U9.3 (VBUS), U9.8 (VAC2), U9.9 (VAC1)
VCP: C83.2, U2.6 (VCP)
VS: C80.1, C83.1, C85.1, C86.1, J10.1, JP2.2 (C), U2.22 (VS), U2.28 (VS)
VSYS: C17.2, C18.2, C19.2, C20.2, C21.2, C25.2, C41.2, C52.2, C53.2, C54.2, C55.2, C94.2, D8.2 (A), JP2.1 (A), TP4.1 (1_1), U9.25 (SYS), U11.2 (VIN), U12.3 (IN), U14.2 (EN), U14.3 (IN)
VUSB: F1.2, USB1.2 (VBUS), USB1.11 (VBUS)

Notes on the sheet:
ESP32
5VHP Buck
Over/discharge protection
Battery
3.3V Buck
Fuel Gauge
5V Buck
USB
Power
Motor Driver
Ethernet (FallBack)
Charger
Audio
Modules
PD Trigger
Ethernet

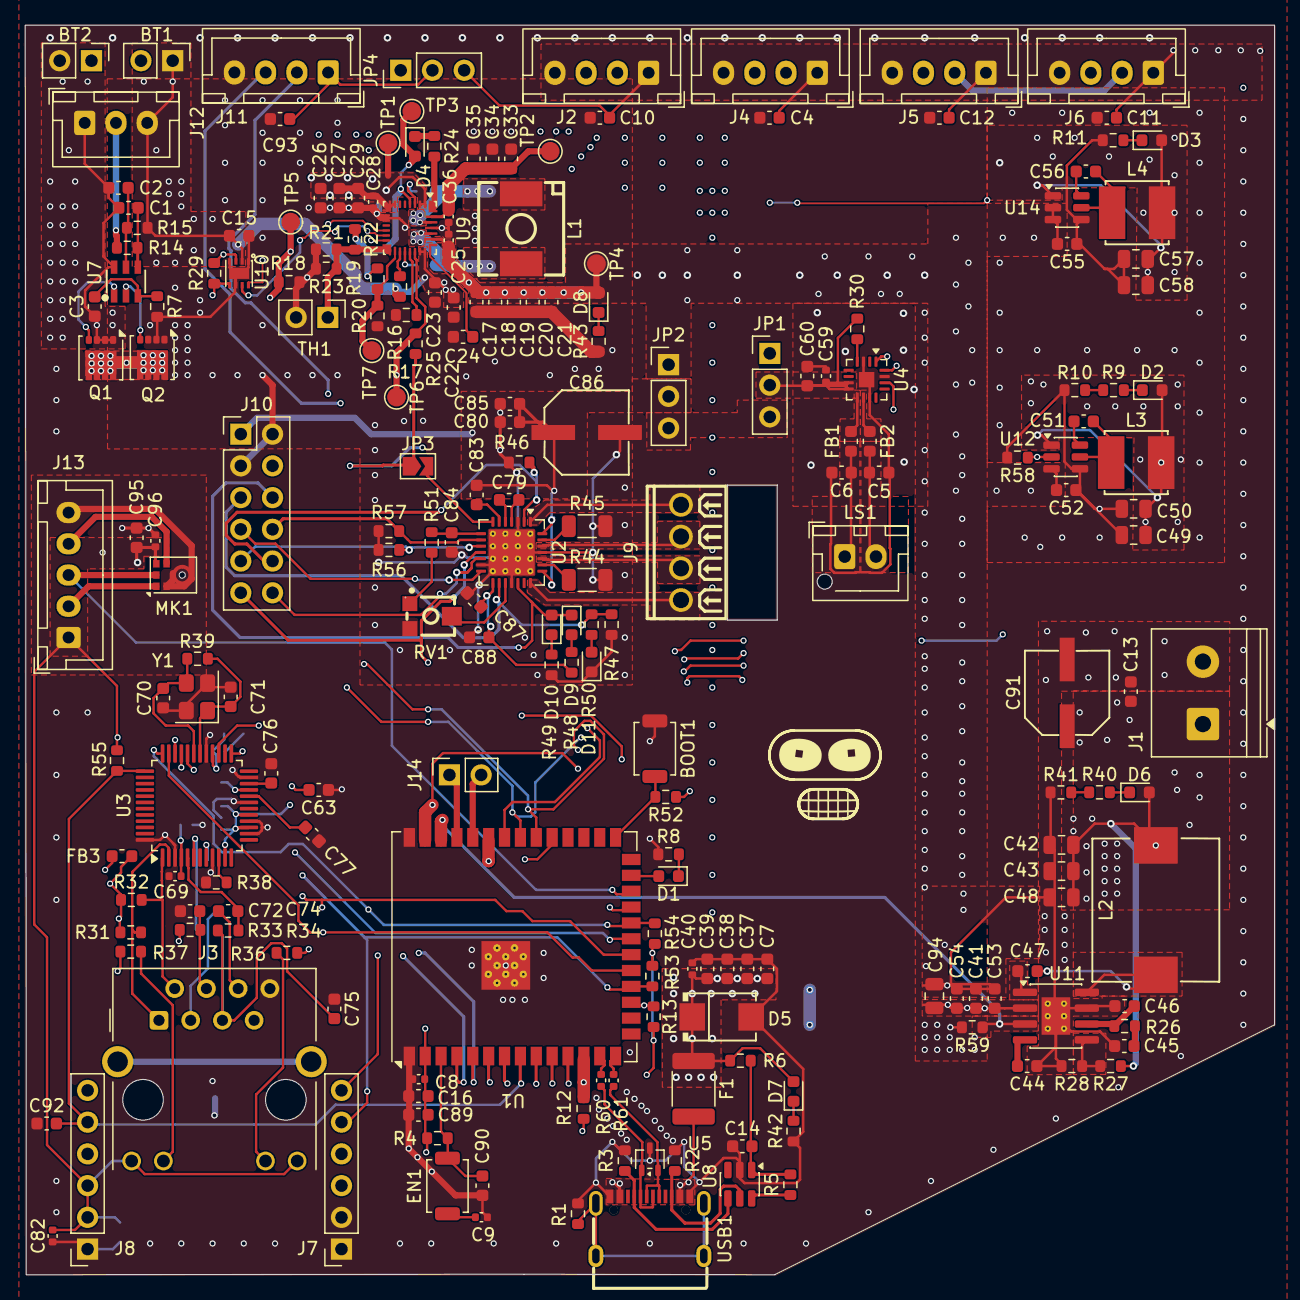
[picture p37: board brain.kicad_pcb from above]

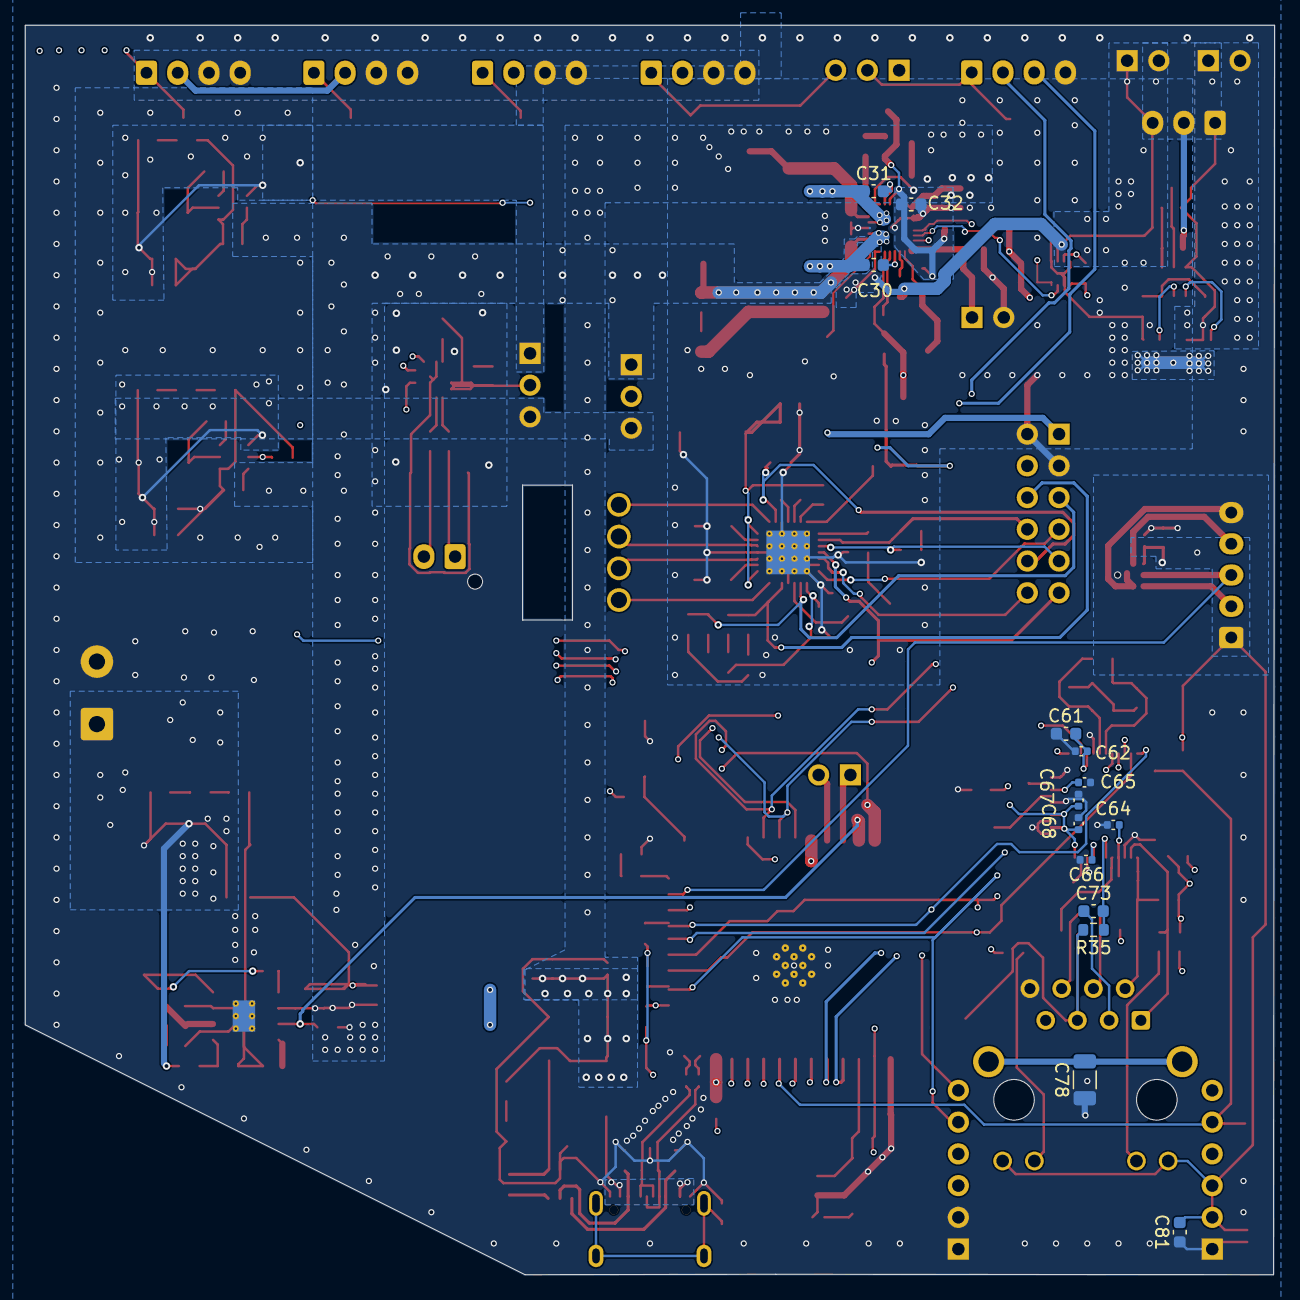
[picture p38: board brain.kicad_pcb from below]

Board: 4 copper layers, 100.0 x 100.0 mm, 225 parts (14 on the bottom side), 132 nets.

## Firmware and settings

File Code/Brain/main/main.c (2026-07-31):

#include <stdbool.h>
#include <ctype.h>
#include <inttypes.h>
#include <stdint.h>
#include <stdio.h>
#include <stdlib.h>
#include <string.h>

#include "driver/gpio.h"
#include "driver/i2c_master.h"
#include "driver/i2s_std.h"
#include "driver/usb_serial_jtag.h"
#include "driver/usb_serial_jtag_vfs.h"
#include "brain_audio.h"
#include "brain_config.h"
#include "brain_workflow.h"
#include "display_protocol.h"
#include "eye_protocol.h"
#include "esp_check.h"
#include "esp_event.h"
#include "esp_eth.h"
#include "esp_eth_mac_spi.h"
#include "esp_eth_netif_glue.h"
#include "esp_eth_phy.h"
#include "esp_http_server.h"
#include "esp_log.h"
#include "esp_netif.h"
#include "esp_system.h"
#include "esp_timer.h"
#include "esp_wifi.h"
#include "freertos/FreeRTOS.h"
#include "freertos/event_groups.h"
#include "freertos/queue.h"
#include "freertos/semphr.h"
#include "freertos/task.h"
#include "mouth_espnow.h"
#include "nvs_flash.h"
#include "driver/spi_master.h"

#define PIN_5V_EN GPIO_NUM_1
#define PIN_5VHP_EN GPIO_NUM_2
#define PIN_CHARGER_CE GPIO_NUM_6
#define PIN_BQ_INT GPIO_NUM_7
#define PIN_I2C_SDA GPIO_NUM_8
#define PIN_I2C_SCL GPIO_NUM_9
#define PIN_ETH_CS GPIO_NUM_10
#define PIN_ETH_MOSI GPIO_NUM_11
#define PIN_ETH_SCLK GPIO_NUM_12
#define PIN_ETH_MISO GPIO_NUM_13
#define PIN_ETH_INT GPIO_NUM_14
#define PIN_ETH_RST GPIO_NUM_15
#define PIN_TMC_STEP GPIO_NUM_16
#define PIN_TMC_DIR GPIO_NUM_17
#define PIN_TMC_EN GPIO_NUM_18
#define PIN_TMC_UART GPIO_NUM_21
#define PIN_TMC_DIAG GPIO_NUM_38
#define PIN_I2S_BCLK GPIO_NUM_39
#define PIN_I2S_LRCLK GPIO_NUM_40
#define PIN_I2S_DOUT GPIO_NUM_41
#define PIN_FUEL_ALERT GPIO_NUM_42
#define PIN_I2S_DIN GPIO_NUM_47
#define PIN_STATUS_LED GPIO_NUM_48

#define I2C_TIMEOUT_MS 80
#define WIFI_CONNECTED_BIT BIT0
#define AI_TASK_STACK_SIZE 24576
#define WORKFLOW_ANSWER_SIZE 8192
#define CLI_INPUT_SIZE 256
#define CLI_HISTORY_DEPTH 12

#define ADDR_LEFT_EYE 0x30
#define ADDR_RIGHT_EYE 0x31

#define PROTO_VERSION EYE_PROTOCOL_VERSION_TRANSITIONS
#define CMD_PING DISPLAY_CMD_PING
#define CMD_GET_INFO DISPLAY_CMD_GET_INFO
#define CMD_SET_BRIGHTNESS DISPLAY_CMD_SET_BRIGHTNESS
#define CMD_SET_ANIMATION DISPLAY_CMD_SET_ANIMATION
#define CMD_SET_EXPRESSION DISPLAY_CMD_SET_EXPRESSION
#define CMD_SYNC DISPLAY_CMD_SYNC
#define CMD_STOP DISPLAY_CMD_STOP
#define CMD_SET_PARAM DISPLAY_CMD_SET_PARAM
#define CMD_DEBUG_FRAME DISPLAY_CMD_DEBUG_FRAME
#define CMD_RESET DISPLAY_CMD_RESET

#define ANIM_IDLE DISPLAY_ANIM_IDLE
#define ANIM_LISTENING DISPLAY_ANIM_LISTENING
#define ANIM_THINKING DISPLAY_ANIM_THINKING
#define ANIM_THINKING_AUDIO DISPLAY_ANIM_THINKING_AUDIO
#define ANIM_THINKING_LONG DISPLAY_ANIM_THINKING_LONG
#define ANIM_SPEAKING DISPLAY_ANIM_SPEAKING
#define ANIM_HAPPY DISPLAY_ANIM_HAPPY
#define ANIM_ANGRY DISPLAY_ANIM_ANGRY
#define ANIM_ERROR DISPLAY_ANIM_ERROR
#define ANIM_SLEEP DISPLAY_ANIM_SLEEP

#define EYE_COUNT 2
#define EYE_LEFT_INDEX 0
#define EYE_RIGHT_INDEX 1
#define EYE_LEFT_MASK (1U << EYE_LEFT_INDEX)
#define EYE_RIGHT_MASK (1U << EYE_RIGHT_INDEX)
#define EYE_BOTH_MASK (EYE_LEFT_MASK | EYE_RIGHT_MASK)

typedef enum {
    STATE_BOOTING,
    STATE_IDLE,
    STATE_LISTENING,
    STATE_THINKING,
    STATE_SPEAKING,
    STATE_ERROR,
    STATE_SLEEP,
} assistant_state_t;

typedef struct {
    const char *name;
    uint8_t address;
    bool present;
    uint8_t last_sequence;
    uint8_t last_result;
    uint8_t role;
    uint8_t fw_major;
    uint8_t fw_minor;
    uint8_t active_animation;
    uint8_t pending_animation;
    uint8_t active_transition_token;
    uint8_t pending_transition_token;
    uint8_t playback_flags;
    uint8_t current_frame;
    uint8_t last_error;
    uint32_t last_seen_ms;
    uint32_t status_read_ms;
    i2c_master_dev_handle_t i2c_handle;
} display_device_t;

typedef struct {
    uint8_t animation;
    bool emergency;
} face_request_t;

typedef struct {
    uint8_t desired_animation;
    uint8_t committed_animation;
    uint8_t token;
    uint8_t waiting_mask;
    uint32_t started_ms;
    bool degraded;
} face_transition_status_t;

static const char *TAG = "sarcasmos-brain";
static display_device_t g_displays[] = {
    {
        .name = "left_eye",
        .address = ADDR_LEFT_EYE,
        .role = EYE_LEFT_INDEX,
        .pending_animation = EYE_PROTOCOL_NO_PENDING_ANIMATION,
    },
    {
        .name = "right_eye",
        .address = ADDR_RIGHT_EYE,
        .role = EYE_RIGHT_INDEX,
        .pending_animation = EYE_PROTOCOL_NO_PENDING_ANIMATION,
    },
};
static assistant_state_t g_state = STATE_BOOTING;
static uint8_t g_sequence = 1;
static uint8_t g_brightness = 160;
static bool g_wifi_connected;
static bool g_wifi_should_connect;
static bool g_ethernet_connected;
static bool g_mouth_initialized;
static bool g_usb_driver_ready;
static bool g_discard_line_feed;
static EventGroupHandle_t g_wifi_events;
static i2c_master_bus_handle_t g_i2c_bus;
static QueueHandle_t g_face_queue;
static SemaphoreHandle_t g_face_mutex;
static SemaphoreHandle_t g_display_mutex;
static httpd_handle_t g_http_server;
static portMUX_TYPE g_mic_stream_lock = portMUX_INITIALIZER_UNLOCKED;
static bool g_mic_stream_enabled;
static bool g_mic_stream_active;
static bool g_mic_stream_stop;
static brain_config_t g_config;
static uint8_t g_post_speech_animation = ANIM_IDLE;
static bool g_weather_post_speech_animation;
static face_transition_status_t g_face_transition = {
    .desired_animation = ANIM_IDLE,
    .committed_animation = ANIM_IDLE,
};

static uint8_t crc8(const uint8_t *data, size_t len)
{
    uint8_t crc = 0;
    for (size_t i = 0; i < len; ++i) {
        crc ^= data[i];
        for (int bit = 0; bit < 8; ++bit) {
            crc = (crc & 0x80) ? (uint8_t)((crc << 1) ^ 0x07) : (uint8_t)(crc << 1);
        }
    }
    return crc;
}

static const char *state_name(assistant_state_t state)
{
    switch (state) {
    case STATE_BOOTING: return "booting";
    case STATE_IDLE: return "idle";
    case STATE_LISTENING: return "listening";
    case STATE_THINKING: return "thinking";
    case STATE_SPEAKING: return "speaking";
    case STATE_ERROR: return "error";
    case STATE_SLEEP: return "sleep";
    default: return "unknown";
    }
}

static uint8_t animation_for_state(assistant_state_t state)
{
    switch (state) {
    case STATE_BOOTING: return ANIM_THINKING;
    case STATE_IDLE: return ANIM_IDLE;
    case STATE_LISTENING: return ANIM_LISTENING;
    case STATE_THINKING: return ANIM_THINKING;
    case STATE_SPEAKING: return ANIM_SPEAKING;
    case STATE_ERROR: return ANIM_ERROR;
    case STATE_SLEEP: return ANIM_SLEEP;
    default: return ANIM_ERROR;
    }
}

static assistant_state_t parse_state(const char *body)
{
    if (strstr(body, "listening")) return STATE_LISTENING;
    if (strstr(body, "thinking_audio")) return STATE_THINKING;
    if (strstr(body, "thinking-long") || strstr(body, "thinking_long")) return STATE_THINKING;
    if (strstr(body, "thinking")) return STATE_THINKING;
    if (strstr(body, "speaking")) return STATE_SPEAKING;
    if (strstr(body, "happy")) return STATE_IDLE;
    if (strstr(body, "angry")) return STATE_ERROR;
    if (strstr(body, "error")) return STATE_ERROR;
    if (strstr(body, "sleep")) return STATE_SLEEP;
    return STATE_IDLE;
}

static uint32_t uptime_ms(void)
{
    return (uint32_t)(esp_timer_get_time() / 1000ULL);
}

static esp_err_t eye_transmit_locked(display_device_t *eye, uint8_t command,
                                     const uint8_t *payload, uint8_t len)
{
    if (eye == NULL || eye->i2c_handle == NULL) {
        return ESP_ERR_NOT_FOUND;
    }
    uint8_t frame[4 + 64 + 1];
    if (len > 64) {
        return ESP_ERR_INVALID_SIZE;
    }
    frame[0] = PROTO_VERSION;
    frame[1] = command;
    frame[2] = g_sequence++;
    if (g_sequence == 0) {
        g_sequence = 1;
    }
    frame[3] = len;
    if (len > 0 && payload != NULL) {
        memcpy(&frame[4], payload, len);
    }
    frame[4 + len] = crc8(frame, 4 + len);
    esp_err_t err =
        i2c_master_transmit(eye->i2c_handle, frame, 5 + len, I2C_TIMEOUT_MS);
    eye->present = err == ESP_OK;
    if (err == ESP_OK) {
        eye->last_sequence = frame[2];
        eye->last_seen_ms = uptime_ms();
    }
    return err;
}

static esp_err_t eye_command(display_device_t *eye, uint8_t command,
                             const uint8_t *payload, uint8_t len)
{
    if (xSemaphoreTake(g_display_mutex, portMAX_DELAY) != pdTRUE) {
        return ESP_FAIL;
    }
    esp_err_t err = eye_transmit_locked(eye, command, payload, len);
    xSemaphoreGive(g_display_mutex);
    return err;
}

static esp_err_t eye_command_both(uint8_t command, const uint8_t *payload,
                                  uint8_t len)
{
    esp_err_t result = ESP_OK;
    for (size_t i = 0; i < EYE_COUNT; ++i) {
        esp_err_t err = eye_command(&g_displays[i], command, payload, len);
        if (err != ESP_OK) {
            result = err;
        }
    }
    return result;
}

static uint8_t eye_commit_ready(uint8_t ready_mask, uint8_t token)
{
    uint8_t committed_mask = 0;
    uint8_t payload[EYE_SYNC_PAYLOAD_SIZE];
    eye_protocol_encode_sync(payload, token, EYE_SYNC_START_DELAY_MS);
    if (xSemaphoreTake(g_display_mutex, portMAX_DELAY) != pdTRUE) {
        return 0;
    }
    for (size_t i = 0; i < EYE_COUNT; ++i) {
        const uint8_t mask = 1U << i;
        if ((ready_mask & mask) == 0) {
            continue;
        }
        esp_err_t err = eye_transmit_locked(
            &g_displays[i], CMD_SYNC, payload, sizeof(payload));
        if (err == ESP_OK) {
            committed_mask |= mask;
            ESP_LOGI(TAG, "%s commit sent token=%u delay=%u ms at %" PRIu32,
                     g_displays[i].name, token, EYE_SYNC_START_DELAY_MS,
                     uptime_ms());
        } else {
            ESP_LOGE(TAG, "%s commit failed: %s",
                     g_displays[i].name, esp_err_to_name(err));
        }
    }
    xSemaphoreGive(g_display_mutex);
    return committed_mask;
}

static esp_err_t mouth_command(uint8_t command, const uint8_t *payload,
                               uint8_t len)
{
#if CONFIG_SARCASMOS_MOUTH_ESPNOW
    if (g_mouth_initialized) {
        return mouth_espnow_send(command, payload, len, true);
    }
    return ESP_ERR_INVALID_STATE;
#else
    (void)command;
    (void)payload;
    (void)len;
    return ESP_ERR_NOT_SUPPORTED;
#endif
}

static esp_err_t display_command_non_animation_all(
    uint8_t command, const uint8_t *payload, uint8_t len)
{
    esp_err_t result = eye_command_both(command, payload, len);
    esp_err_t mouth_err = mouth_command(command, payload, len);
    if (mouth_err != ESP_OK && mouth_err != ESP_ERR_NOT_SUPPORTED &&
        mouth_err != ESP_ERR_INVALID_STATE) {
        result = mouth_err;
    }
    return result;
}

static esp_err_t eye_read_status(display_device_t *eye,
                                 eye_protocol_status_t *status)
{
    if (eye == NULL || status == NULL ||
        xSemaphoreTake(g_display_mutex, portMAX_DELAY) != pdTRUE) {
        return ESP_ERR_INVALID_ARG;
    }

    uint8_t response[EYE_PROTOCOL_STATUS_SIZE] = { 0 };
    esp_err_t err = i2c_master_receive(
        eye->i2c_handle, response, sizeof(response), I2C_TIMEOUT_MS);
    if (err == ESP_OK &&
        !eye_protocol_decode_status(response, sizeof(response), eye->role,
                                    status)) {
        err = ESP_ERR_INVALID_RESPONSE;
    }
    if (err == ESP_OK &&
        (status->active_animation >= DISPLAY_ANIM_COUNT ||
         (status->pending_animation != EYE_PROTOCOL_NO_PENDING_ANIMATION &&
          status->pending_animation >= DISPLAY_ANIM_COUNT))) {
        err = ESP_ERR_INVALID_RESPONSE;
    }
    if (err == ESP_OK) {
        eye->present = true;
        eye->fw_major = status->firmware_major;
        eye->fw_minor = status->firmware_minor;
        eye->active_animation = status->active_animation;
        eye->pending_animation = status->pending_animation;
        eye->active_transition_token = status->active_transition_token;
        eye->pending_transition_token = status->pending_transition_token;
        eye->playback_flags = status->playback_flags;
        eye->current_frame = status->current_frame;
        eye->last_result = status->last_error;
        eye->last_error = status->last_error;
        eye->status_read_ms = uptime_ms();
        eye->last_seen_ms = eye->status_read_ms;
    }
    xSemaphoreGive(g_display_mutex);
    return err;
}

static bool emergency_animation(uint8_t animation)
{
    return animation == ANIM_ERROR || animation == ANIM_SLEEP ||
           animation == DISPLAY_ANIM_BATTERY_LOW;
}

static esp_err_t request_face_state(uint8_t animation, bool emergency)
{
    if (animation >= DISPLAY_ANIM_COUNT || g_face_queue == NULL) {
        return ESP_ERR_INVALID_ARG;
    }
    face_request_t request = {
        .animation = animation,
        .emergency = emergency || emergency_animation(animation),
    };
    if (xSemaphoreTake(g_face_mutex, portMAX_DELAY) == pdTRUE) {
        g_face_transition.desired_animation = animation;
        xSemaphoreGive(g_face_mutex);
    }
    return xQueueOverwrite(g_face_queue, &request) == pdPASS
               ? ESP_OK : ESP_FAIL;
}

static void configure_gpio(void)
{
    gpio_config_t out = {
        .pin_bit_mask = (1ULL << PIN_5V_EN) | (1ULL << PIN_5VHP_EN) | (1ULL << PIN_CHARGER_CE) |
                        (1ULL << PIN_STATUS_LED) | (1ULL << PIN_ETH_RST) | (1ULL << PIN_TMC_EN) |
                        (1ULL << PIN_TMC_STEP) | (1ULL << PIN_TMC_DIR),
        .mode = GPIO_MODE_OUTPUT,
    };
    ESP_ERROR_CHECK(gpio_config(&out));
    gpio_set_level(PIN_5V_EN, 1);
    gpio_set_level(PIN_5VHP_EN, 1);
    gpio_set_level(PIN_CHARGER_CE, 0);
    gpio_set_level(PIN_ETH_RST, 1);
    gpio_set_level(PIN_TMC_EN, 1);
    gpio_set_level(PIN_STATUS_LED, 0);

    gpio_config_t in = {
        .pin_bit_mask = (1ULL << PIN_BQ_INT) | (1ULL << PIN_FUEL_ALERT) | (1ULL << PIN_ETH_INT) | (1ULL << PIN_TMC_DIAG),
        .mode = GPIO_MODE_INPUT,
        .pull_up_en = GPIO_PULLUP_ENABLE,
    };
    ESP_ERROR_CHECK(gpio_config(&in));
}

static void configure_i2c(void)
{
    i2c_master_bus_config_t bus_cfg = {
        .i2c_port = I2C_NUM_0,
        .sda_io_num = PIN_I2C_SDA,
        .scl_io_num = PIN_I2C_SCL,
        .clk_source = I2C_CLK_SRC_DEFAULT,
        .glitch_ignore_cnt = 7,
        .flags.enable_internal_pullup = false,
    };
    ESP_ERROR_CHECK(i2c_new_master_bus(&bus_cfg, &g_i2c_bus));

    for (size_t i = 0; i < sizeof(g_displays) / sizeof(g_displays[0]); ++i) {
        i2c_device_config_t dev_cfg = {
            .dev_addr_length = I2C_ADDR_BIT_LEN_7,
            .device_address = g_displays[i].address,
            .scl_speed_hz = CONFIG_SARCASMOS_I2C_FREQ_HZ,
        };
        ESP_ERROR_CHECK(i2c_master_bus_add_device(g_i2c_bus, &dev_cfg, &g_displays[i].i2c_handle));
    }
}

static void wifi_event_handler(void *arg, esp_event_base_t base, int32_t event_id, void *event_data)
{
    if (base == WIFI_EVENT && event_id == WIFI_EVENT_STA_START) {
        if (g_wifi_should_connect) {
            esp_wifi_connect();
        }
    } else if (base == WIFI_EVENT && event_id == WIFI_EVENT_STA_DISCONNECTED) {
        g_wifi_connected = false;
        xEventGroupClearBits(g_wifi_events, WIFI_CONNECTED_BIT);
        if (g_wifi_should_connect) {
            esp_wifi_connect();
        }
    } else if (base == IP_EVENT && event_id == IP_EVENT_STA_GOT_IP) {
        g_wifi_connected = true;
        xEventGroupSetBits(g_wifi_events, WIFI_CONNECTED_BIT);
    }
}

static void ensure_netif_event_loop(void)
{
    esp_err_t err = esp_netif_init();
    if (err != ESP_OK && err != ESP_ERR_INVALID_STATE) ESP_ERROR_CHECK(err);
    err = esp_event_loop_create_default();
    if (err != ESP_OK && err != ESP_ERR_INVALID_STATE) ESP_ERROR_CHECK(err);
}

static esp_err_t start_wifi(void)
{
#if CONFIG_SARCASMOS_ENABLE_WIFI || CONFIG_SARCASMOS_MOUTH_ESPNOW
    ensure_netif_event_loop();
    esp_netif_create_default_wifi_sta();
    g_wifi_events = xEventGroupCreate();
    if (g_wifi_events == NULL) {
        return ESP_ERR_NO_MEM;
    }
    wifi_init_config_t cfg = WIFI_INIT_CONFIG_DEFAULT();
    ESP_RETURN_ON_ERROR(esp_wifi_init(&cfg), TAG, "Wi-Fi init failed");
    ESP_RETURN_ON_ERROR(esp_event_handler_register(
                            WIFI_EVENT, ESP_EVENT_ANY_ID,
                            wifi_event_handler, NULL),
                        TAG, "Wi-Fi event registration failed");
    ESP_RETURN_ON_ERROR(esp_event_handler_register(
                            IP_EVENT, IP_EVENT_STA_GOT_IP,
                            wifi_event_handler, NULL),
                        TAG, "IP event registration failed");
    ESP_RETURN_ON_ERROR(esp_wifi_set_storage(WIFI_STORAGE_RAM),
                        TAG, "Wi-Fi storage setup failed");
    ESP_RETURN_ON_ERROR(esp_wifi_set_mode(WIFI_MODE_STA),
                        TAG, "Wi-Fi mode setup failed");

#if CONFIG_SARCASMOS_ENABLE_WIFI
    g_wifi_should_connect = strlen(g_config.wifi_ssid) > 0;
    if (g_wifi_should_connect) {
        wifi_config_t wifi_config = { 0 };
        strlcpy((char *)wifi_config.sta.ssid, g_config.wifi_ssid,
                sizeof(wifi_config.sta.ssid));
        strlcpy((char *)wifi_config.sta.password, g_config.wifi_password,
                sizeof(wifi_config.sta.password));
        wifi_config.sta.threshold.authmode = WIFI_AUTH_WPA2_PSK;
        ESP_RETURN_ON_ERROR(esp_wifi_set_config(WIFI_IF_STA, &wifi_config),
                            TAG, "Wi-Fi config failed");
    }
#endif

    ESP_RETURN_ON_ERROR(esp_wifi_start(), TAG, "Wi-Fi start failed");
    if (g_wifi_should_connect) {
        EventBits_t bits = xEventGroupWaitBits(
            g_wifi_events, WIFI_CONNECTED_BIT, pdFALSE, pdFALSE,
            pdMS_TO_TICKS(15000));
        if ((bits & WIFI_CONNECTED_BIT) == 0) {
            ESP_LOGW(TAG, "Wi-Fi connection timed out; ESP-NOW may use the wrong channel");
        }
    } else {
#if CONFIG_SARCASMOS_MOUTH_ESPNOW
        ESP_RETURN_ON_ERROR(
            esp_wifi_set_channel(CONFIG_SARCASMOS_ESPNOW_CHANNEL,
                                 WIFI_SECOND_CHAN_NONE),
            TAG, "ESP-NOW channel setup failed");
#endif
    }
    return ESP_OK;
#else
    return ESP_ERR_NOT_SUPPORTED;
#endif
}
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
void app_main(void)
{
    vTaskDelay(pdMS_TO_TICKS(300));
    usb_serial_jtag_driver_config_t usb_config =
        USB_SERIAL_JTAG_DRIVER_CONFIG_DEFAULT();
    esp_err_t usb_err = usb_serial_jtag_driver_install(&usb_config);
    if (usb_err == ESP_OK) {
        usb_serial_jtag_vfs_use_driver();
        g_usb_driver_ready = true;
    }
    setvbuf(stdin, NULL, _IONBF, 0);
    setvbuf(stdout, NULL, _IONBF, 0);

    esp_err_t nvs = nvs_flash_init();
    if (nvs == ESP_ERR_NVS_NO_FREE_PAGES || nvs == ESP_ERR_NVS_NEW_VERSION_FOUND) {
        ESP_ERROR_CHECK(nvs_flash_erase());
        ESP_ERROR_CHECK(nvs_flash_init());
    }
    ESP_ERROR_CHECK(brain_config_load(&g_config));
    ESP_ERROR_CHECK(brain_audio_set_mic_gain_q8(g_config.mic_gain_q8));
    ESP_ERROR_CHECK(brain_audio_set_speaker_gain_q8(
        g_config.speaker_gain_q8));
    g_face_queue = xQueueCreate(1, sizeof(face_request_t));
    g_face_mutex = xSemaphoreCreateMutex();
    g_display_mutex = xSemaphoreCreateMutex();
    ESP_ERROR_CHECK(g_face_queue != NULL && g_face_mutex != NULL &&
                            g_display_mutex != NULL
                        ? ESP_OK : ESP_ERR_NO_MEM);

    configure_gpio();
    configure_i2c();
    esp_err_t audio_err = brain_audio_init();
    if (audio_err != ESP_OK) {
        ESP_LOGE(TAG, "I2S audio init failed: %s",
                 esp_err_to_name(audio_err));
    }
    ESP_ERROR_CHECK(brain_workflow_init(
        workflow_event_handler, NULL));
    esp_err_t wifi_err = start_wifi();
    if (wifi_err != ESP_OK && wifi_err != ESP_ERR_NOT_SUPPORTED) {
        ESP_LOGE(TAG, "Wi-Fi radio start failed: %s", esp_err_to_name(wifi_err));
    }
    if (wifi_err == ESP_OK) {
        start_mouth_espnow();
    }
    start_ethernet();

    vTaskDelay(pdMS_TO_TICKS(250));
    display_command_non_animation_all(
        CMD_SET_BRIGHTNESS, &g_brightness, 1);

    ESP_ERROR_CHECK(xTaskCreate(
        face_transition_task, "face_transition", 6144, NULL, 6, NULL) == pdPASS
                        ? ESP_OK : ESP_ERR_NO_MEM);
    ESP_ERROR_CHECK(xTaskCreate(
        display_health_task, "display_health", 4096, NULL, 5, NULL) == pdPASS
                        ? ESP_OK : ESP_ERR_NO_MEM);
    ESP_ERROR_CHECK(xTaskCreate(
        state_led_task, "state_led", 2048, NULL, 4, NULL) == pdPASS
                        ? ESP_OK : ESP_ERR_NO_MEM);

    g_state = STATE_IDLE;
    ESP_ERROR_CHECK(request_face_state(ANIM_IDLE, false));
    start_http_server();

    ESP_LOGI(TAG, "SarcasmOS brain ready");
    if (usb_err != ESP_OK) {
        ESP_LOGW(TAG, "USB byte driver unavailable: %s",
                 esp_err_to_name(usb_err));
    }
    ESP_ERROR_CHECK(xTaskCreate(
        cli_task, "brain_cli", AI_TASK_STACK_SIZE, NULL, 3, NULL) == pdPASS
                        ? ESP_OK : ESP_ERR_NO_MEM);
    ESP_ERROR_CHECK(xTaskCreate(
        workflow_wake_task, "workflow_wake", AI_TASK_STACK_SIZE,
        NULL, 3, NULL) == pdPASS
                        ? ESP_OK : ESP_ERR_NO_MEM);
}

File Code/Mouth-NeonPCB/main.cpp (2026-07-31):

// SPDX-License-Identifier: MIT

#include <Arduino.h>
#include <Preferences.h>
#include <WiFi.h>
#include <esp_now.h>
#include <esp_wifi.h>

#include "mouth_display.hpp"
#include "channel_button.hpp"
#include "protocol.hpp"

#ifndef ESPNOW_CHANNEL
#define ESPNOW_CHANNEL 1
#endif

namespace {

using namespace mouth_protocol;

constexpr uint8_t kFirmwareMajor = 3;
constexpr uint8_t kFirmwareMinor = 3;
constexpr uint8_t kChannelButtonPin = 0;
constexpr char kPreferencesNamespace[] = "mouth-radio";
constexpr char kChannelPreferenceKey[] = "channel";

struct PendingPacket {
    uint8_t source[6];
    uint8_t data[kMaxPacketSize];
    size_t length;
};

portMUX_TYPE receiveMux = portMUX_INITIALIZER_UNLOCKED;
PendingPacket pendingPacket = {};
volatile bool packetReady = false;

uint8_t lastSequence = 0;
uint8_t lastError = kErrorNone;
uint8_t lastSender[6] = {};
bool haveLastSender = false;
bool espNowReady = false;
bool preferencesReady = false;
uint8_t espNowChannel = ESPNOW_CHANNEL;
Preferences preferences;
mouth_channel::ButtonState channelButton;

bool sameMac(const uint8_t *left, const uint8_t *right) {
    return memcmp(left, right, 6) == 0;
}

void printMac(const uint8_t *mac) {
    Serial.printf("%02X:%02X:%02X:%02X:%02X:%02X",
                  mac[0], mac[1], mac[2], mac[3], mac[4], mac[5]);
}

bool ensurePeer(const uint8_t *mac) {
    if (esp_now_is_peer_exist(mac)) return true;

    esp_now_peer_info_t peer = {};
    memcpy(peer.peer_addr, mac, 6);
    peer.channel = espNowChannel;
    peer.ifidx = WIFI_IF_STA;
    peer.encrypt = false;
    const esp_err_t result = esp_now_add_peer(&peer);
    if (result != ESP_OK) {
        Serial.printf("ESP-NOW add peer failed: %s\n", esp_err_to_name(result));
        return false;
    }
    return true;
}

void sendStatus(const uint8_t *destination, uint8_t command) {
    if (!ensurePeer(destination)) return;

    const uint8_t payload[kStatusPayloadSize] = {
        kApplicationVersion,
        kRoleMouth,
        kFirmwareMajor,
        kFirmwareMinor,
        mouth_display::animation(),
        lastSequence,
        lastError,
        mouth_display::brightness(),
        mouth_display::mouthIntensity(),
        espNowChannel,
        mouth_display::transitionToken(),
        static_cast<uint8_t>(mouth_display::transitionActive() ? 1 : 0),
        mouth_display::transitionProgress(),
    };
    uint8_t response[kMaxPacketSize];
    const size_t length = encodePacket(
        response, sizeof(response), kTypeStatus, kRoleMouth, lastSequence,
        command, payload, sizeof(payload));
    const esp_err_t result = esp_now_send(destination, response, length);
    if (result != ESP_OK) {
        Serial.printf("ESP-NOW status queue failed: %s\n", esp_err_to_name(result));
    }
}

void onDataReceived(const uint8_t *mac, const uint8_t *data, int length) {
    if (mac == nullptr || data == nullptr || length <= 0 ||
        length > static_cast<int>(kMaxPacketSize)) {
        return;
    }

    portENTER_CRITICAL(&receiveMux);
    if (!packetReady) {
        memcpy(pendingPacket.source, mac, 6);
        memcpy(pendingPacket.data, data, length);
        pendingPacket.length = static_cast<size_t>(length);
        packetReady = true;
    }
    portEXIT_CRITICAL(&receiveMux);
}

bool takePendingPacket(PendingPacket &packet) {
    bool available = false;
    portENTER_CRITICAL(&receiveMux);
    if (packetReady) {
        packet = pendingPacket;
        packetReady = false;
        available = true;
    }
    portEXIT_CRITICAL(&receiveMux);
    return available;
}

bool requirePayload(const PacketView &packet, uint8_t minimum) {
    if (packet.payloadLength >= minimum) return true;
    lastError = kErrorInvalidPayload;
    return false;
}

bool processCommand(const PacketView &packet) {
    switch (packet.command) {
    case kCmdPing:
    case kCmdGetInfo:
        return true;
    case kCmdSetBrightness:
        if (!requirePayload(packet, 1)) return false;
        mouth_display::setBrightness(packet.payload[0]);
        return true;
    case kCmdSetAnimation:
    case kCmdSetExpression:
        if (!requirePayload(packet, 1)) return false;
        if (!isValidAnimation(packet.payload[0])) {
            lastError = kErrorInvalidPayload;
            return false;
        }
        mouth_display::requestAnimation(
            packet.payload[0],
            packet.payloadLength >= 2 ? packet.payload[1] : 0,
            packet.payloadLength >= 3 && packet.payload[2] != 0
                ? static_cast<uint16_t>(packet.payload[2]) *
                      mouth_display::kRendererFrameIntervalMs
                : mouth_display::kDefaultTransitionDurationMs
        );
        return true;
    case kCmdSync:
        if (!requirePayload(packet, 4)) return false;
        mouth_display::setSyncPhase(
            static_cast<uint32_t>(packet.payload[0]) |
            (static_cast<uint32_t>(packet.payload[1]) << 8) |
            (static_cast<uint32_t>(packet.payload[2]) << 16) |
            (static_cast<uint32_t>(packet.payload[3]) << 24));
        return true;
    case kCmdStop:
        mouth_display::requestAnimation(kAnimSleep);
        return true;
    case kCmdSetParam:
        if (!requirePayload(packet, 2)) return false;
        if (packet.payload[0] == kParamMouthIntensity) {
            mouth_display::setMouthIntensity(packet.payload[1]);
            return true;
        }
        if (packet.payload[0] == kParamTemperatureCelsius) {
            const int16_t signedValue = packet.payload[1] <= INT8_MAX
                                            ? packet.payload[1]
                                            : packet.payload[1] - 256;
            mouth_display::setTemperatureCelsius(
                static_cast<int8_t>(signedValue));
            return true;
        }
        lastError = kErrorInvalidPayload;
        return false;
    case kCmdReset:
        return true;
    default:
        lastError = kErrorUnknownCommand;
        return false;
    }
}
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

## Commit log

2026-04-04 Create interior SarcasmOS.FCStd
    [interior SarcasmOS.FCStd]
2026-04-04 head, wip
    [Head.FCStd]
2026-04-06 This is the bass whith and without top lid
    [Bass bemder with a top lid.FCStd, Bass bemder without a top lid.FCStd]
2026-04-17 more audios
    [out.csv]
2026-04-18 audio grades base done
    [audio_grades.csv]
2026-04-19 very good audio
    [audio_grades.csv]
2026-05-06 Piannote test
    [bender-voz4.tsv]
2026-05-16 Start of the Eye PCB
    [eye.kicad_pcb, eye.kicad_sch]
2026-05-16 continue with rp2040
    [eye.kicad_sch]
2026-05-17 finish schematic
    [eye.kicad_pcb, eye.kicad_sch]
2026-05-17 add buttons
    [eye.kicad_sch]
2026-05-17 finish placement
    [eye.kicad_pcb, eye.kicad_sch]
2026-05-17 mostly routed
    [eye.kicad_pcb]
2026-05-18 bigger vias
    [bom.csv, designators.csv, eye.kicad_pcb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]
2026-05-18 continue routing
    [eye.kicad_pcb]
2026-05-18 fix all DRC errors
    [eye.kicad_pcb]
2026-05-18 finish Eye PCB
    [bom.csv, designators.csv, eye.kicad_pcb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]
2026-05-19 BOM + improvements
    [bom.csv, designators.csv, eye.kicad_pcb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]
2026-05-20 mouth pcb
    [bom.csv, designators.csv, mouth.kicad_pcb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]
2026-05-20 continue on mouth PCB
    [mouth.kicad_sch]
2026-05-21 start placing Mouth PCB components
    [mouth.kicad_pcb, mouth.kicad_sch]
2026-05-23 more pcb
    [mouth.kicad_pcb, mouth.kicad_sch]
2026-05-23 finish mouth pcb
    [mouth.kicad_pcb]
2026-05-24 eye pcb
    [eye.kicad_pcb]
2026-05-27 over/discharge prot + Fuel Gauge
    [brain.kicad_pcb, brain.kicad_sch]
2026-05-29 mostly do power part
    [bom.csv, designators.csv, mouth.kicad_pcb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]
2026-05-29 switch to minimax/speech-2.8-turbo
2026-05-29 buck HP done
2026-06-01 start working on esp32
    [brain.kicad_sch]
2026-06-01 brain sch done
    [brain.kicad_sch]
2026-06-02 add footprints to BrainPCB
    [brain.kicad_pcb, brain.kicad_sch]
2026-06-03 start pcb routing
    [brain.kicad_pcb, brain.kicad_sch]
2026-06-03 TMC2209 done
    [brain.kicad_pcb]
2026-06-04 Add edit profile button and update stylesheets for profile editing
2026-06-04 more pcb routing
    [brain.kicad_pcb, brain.kicad_sch]
2026-06-05 Enhance support functionality by adding context classification and abuse reporting features. Update user data structure to track support abuse counts and ban statuses. Modify support request handling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
2026-06-07 feat: Implement theme toggle and text streaming functionality
    - Added theme toggle feature to switch between light and dark modes.
    - Implemented theme persistence using localStorage.
    - Enhanced user interface with new styles for light mode.
    - Introduced WebSocket support for streaming text responses from the backend.
    - Updated backend to handle streaming text requests and send responses in chunks.
    - Improved error handling for WebSocket connections.
    - Added new audio output files for synthesized speech responses.
2026-06-07 start component placing on pcb
    [brain.kicad_pcb, brain.kicad_sch]
2026-06-08 moar pcb
    [brain.kicad_pcb, brain.kicad_sch]
2026-06-08 4layer brain pcb
    [brain.kicad_pcb]
2026-06-13 finsihed pcb?
2026-06-13 more DRC
    [brain.kicad_pcb]
2026-06-13 no DRC ERRORS
    [brain.kicad_pcb]
2026-06-13 no DRC important warnings
    [brain.kicad_pcb]
2026-06-13 make pcb fit into 100x100mm area
    [bom.csv, brain.kicad_pcb, designators.csv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]
2026-06-13 fix DRC
    [brain.kicad_pcb]
2026-06-13 sarcasmos logo
    [brain.kicad_pcb, positions.csv]
2026-06-13 finish pcb fr
    [brain.kicad_pcb]
2026-06-13 export PCBs
    [BRAIN.step, EYE.step, MOUTH.step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]
2026-06-15 New bass
    [New bass bender.FCStd]
2026-06-15 visor w/ pcbs
    [newSarcasmos.FCStd]
2026-06-15 fix: visor w/ pcbs
    [newSarcasmos.FCStd]
2026-06-15 top, colors and fixes
    [ASM.FCStd, newSarcasmos.FCStd]
2026-06-16 motor Hole
    [ASM.FCStd, newSarcasmos.FCStd]
2026-06-16 unify BOM
    [bom.csv, eye.kicad_pcb, eye.kicad_sch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]
2026-06-17 add more components to bom
    [bom.csv, unified_bom.csv]
2026-06-18 remove duplicates
    [bom.csv, lcsc_stock_check.csv, unified_bom.csv]
2026-06-19 add prices
    [bom.csv, lcsc_alternative_candidates.csv, lcsc_alternative_recommendations.csv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]
2026-06-19 nvm, remove price
    [unified_bom.csv]
2026-06-19 poster carpet
    [MOUTH.step]
2026-06-20 stuff done
    [SarcasmOS.blend, lcsc_moq_check.csv, mouth.step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]
2026-06-20 Add BOM
    [BOM.csv]
2026-06-20 Why did we build this?
    [SarcasmOS.blend]
2026-06-23 fix exports
    [headBody.step, headTop.step, visor.step]
2026-06-23 move interiorSarcsamos
    [interior SarcasmOS.FCStd]
2026-07-18 new new new final fr real 100% new final bender
    [newBender2.0.FCStd]
2026-07-18 continue bender
    [newBender2.0.FCStd]
2026-07-18 bender done? again?
    [newBender2.0.FCStd]
2026-07-22 fix base-bottom size
    [newBender2.0-Mid.step, newBender2.0-MotorJoint.step, newBender2.0-Visor.step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]
2026-07-22 add antenna hole
    [newBender2.0-cover.step]
2026-07-23 fix i2c interrupt startup
    [main.cpp]
2026-07-24 add esp32-s3 matrix test
2026-07-24 replace life demo with rgb test
    [main.cpp]
2026-07-24 match matrix driver pinout
2026-07-27 add brain board self-test firmware
2026-07-27 add interactive board test menu
2026-07-27 fix serial menu prompt spam
    [main.c]
2026-07-27 fix immediate serial input echo
    [main.c]
2026-07-27 test wireless mouth controller
2026-07-27 add supports to mid
    [newBender2.0-Mid.step, newBender2.0.FCStd]
2026-07-27 fix I2S stream timeout
    [main.c]
2026-07-27 add frame editing controls
2026-07-27 add animation frame sequence editing
2026-07-27 add weather temperature overlay
2026-07-27 add animation frame controls
2026-07-27 add animation frame timing control
2026-07-28 add manual frame stepping
2026-07-28 fix SWD monitor attach
2026-07-29 add frame timeline editor
2026-07-29 split frame playback and auto scroll
2026-07-29 add button hover tooltips
2026-07-29 show space state shortcut
    [main.c]
2026-07-29 fix eye transition polling
    [main.c]
2026-07-29 extend speaker power levels
2026-07-30 fix right eye orientation
    [main.cpp]
2026-07-30 add production duplex audio driver
2026-07-30 integrate streamed Bender voice workflow
    [partitions.csv]
2026-07-30 parse weather temperature for mouth
2026-07-30 run AI workflow on ESP32
2026-07-30 Revert "parse weather temperature for mouth"
    This reverts commit ff09fe706577bde2f58865269574eb3d1a87adb1.
2026-07-31 silence speaker dma underruns
2026-07-31 trust cross-signed tls chains
2026-07-31 add button channel selection
2026-07-31 fix AI task stack overflow
    [main.c]
2026-08-04 3d printer plate
2026-08-04 pcbs iboms
